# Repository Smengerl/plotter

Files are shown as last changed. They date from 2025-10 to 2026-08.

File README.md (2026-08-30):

# G-code Pen Plotter







> ⚠️ **Work in progress.** This project is under active development — hardware
> wiring, firmware configuration and the software pipeline are all still
> changing, and some documents have drifted apart during past refactors.
> Known contradictions and errors are tracked in **[TODO.md](TODO.md)**;
> inline `TODO:` markers in the docs point there. Expect updates.

This plotter draws vector graphics in G-code format using a pen. It is compatible with pens up to 11 mm in diameter, relies on inexpensive and widely available components, and uses a mostly 3D-printed frame with a few off-the-shelf mechanical parts. A set of test cases guides the user to verify the functionality of each hardware component before running GRBL.

The plotter's firmware is based on GRBL v1.1, which is a widely used open-source CNC controller firmware.
It comes with a GUI toolset to transform images provided by the user to drawings in different styles via AI (technical drawing, pencil drawing, oil painting etc.) to send them to the plotter for drawing.

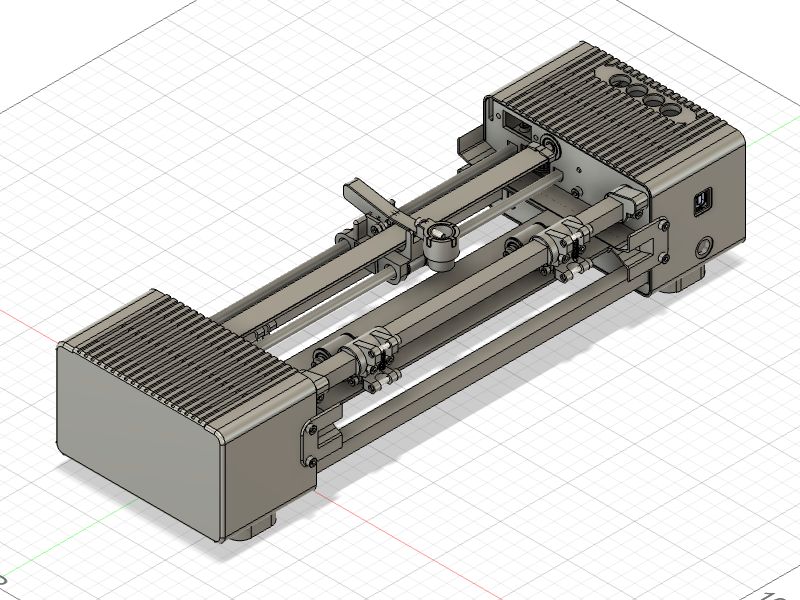
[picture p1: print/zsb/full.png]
Assembly overview


# Table of contents

- [Overview](#overview)
- [Features](#features)
- [Bill of Materials](#bill-of-materials)
- [Assembly](#assembly)
- [Electronics](#electronics) — see [electronics.md](electronics.md) for full details
- [Firmware](#firmware) — see [firmware/README.md](firmware/README.md) for full details
- [Testing & commissioning](#testing) — see [testing.md](testing.md) for the full procedure
- [Software for host computer](#software-for-host-computer) — see [pipeline/README.md](pipeline/README.md) for full details
- [Acknowledgements](#acknowledgements)
- [License](#license)

## Overview

This pen plotter is meant for hobbyists and makers who want a low-cost machine to draw vector artwork on paper. It uses two stepper-driven axes, a simple pen carriage with a lift mechanism via solenoid for automated pen up/down control. Most structural parts are 3D-printed and a number of standard mechanical parts (rods, bearings, springs, belt and pulleys) complete the build.

## Features

- Compatible with pens up to 11 mm diameter
- Mostly 3D-printed components for easy reproduction
- Designed for A4-sized paper by default (adjustable)
- Open-source firmware based on GRBL v1.1
- Test suite to verify hardware functionality before running GRBL
- GUI toolset for image-to-G-code conversion with AI-based drawing styles (technical, pencil, oil painting etc.)

## Bill of Materials

Below are the main 3D-printed parts and standard hardware used in the project. See the [full BOM](BOM.md) and the `print/` directory for the source STL/PNG files and visual references.

### 3D-printed parts (selected)

Refer to the `print/stl/` and `print/png/` folders for all printable parts and preview images.

- `frame_front.stl`, `frame_back.stl` — frame halves
- `housing_front.stl`, `housing_back.stl`, `housing_feet.stl` — optional housing
- `carriage_penholder_base.stl`, `carriage_penholder_connector_screw.stl` — carriage and pen holder
- `flat_steel_flange.stl`, `flat_steel_lever.stl` — parts that interface with the steel pen-raising strip
- `paper_bail_*.stl` — paper bail and rollers
- `paper_guide_front.stl`, `paper_guide_back.stl` — paper gudie
- `shaft_end_flange.stl`, `shaft_connector_flange.stl` — shaft support parts
- `solenoid_slider.stl` — slider to make the pull solenoid a push solenoid (optional)
- `cable_management.stl` — optional cable management clips

### Standard hardware (selected)

- 12 mm square rods
- 6 mm round rods
- 12 mm steel shaft
- 2x 6mm linear ball bearings
- 2x NEMA 17 stepper motors
- 2GT 5mm timing belt, timing pulley and idler pulley
- Assorted M2/M3/M4 screws and nuts (details in original BOM)
- Bearings: F624ZZ bearings used in the rollers
- Springs: compression and extension springs as needed for pen lift and paper drive
- Pull solenoid 12 V (example: TAU-0530)

For a complete part list including quantities and McMaster/AliExpress references, see the original [BOM](BOM.md) in the repository.

## Assembly

The repository contains step-by-step photos and GIFs in `print/zsb/` that show how parts fit together. The high-level assembly steps are:

1. Prepare the back frame: press in M3 nuts, install bearings, fit the timing-belt pulley and mount the optical endstop and solenoid.

2. Prepare the front frame: press in M3 nuts, install bearings, attach stepper motor and shaft coupler, and mount the drive pulley and endstop.

3. Join both frame halves: insert the paper guide rods, shaft, and the movable flat-steel strip used for pen lifting.

Fully assembled lever mechanism:
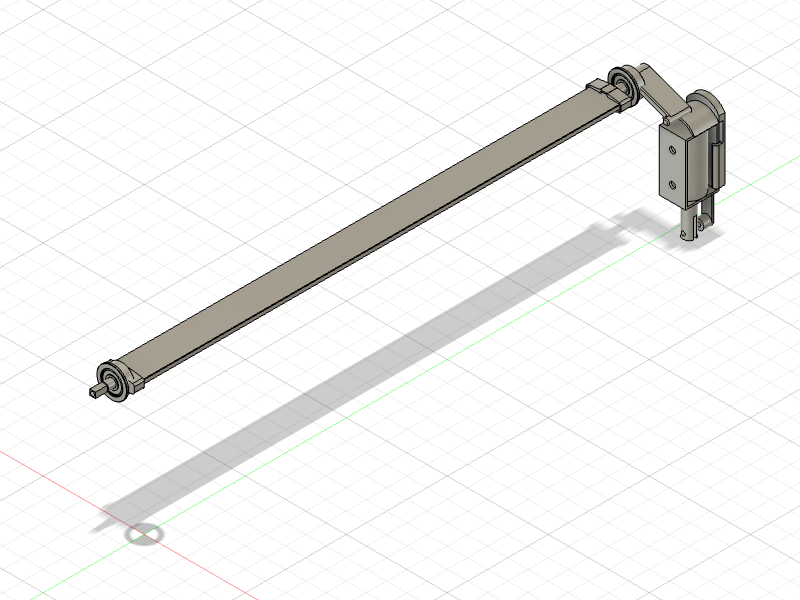
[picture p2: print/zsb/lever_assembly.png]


Fully assembled drive shaft:
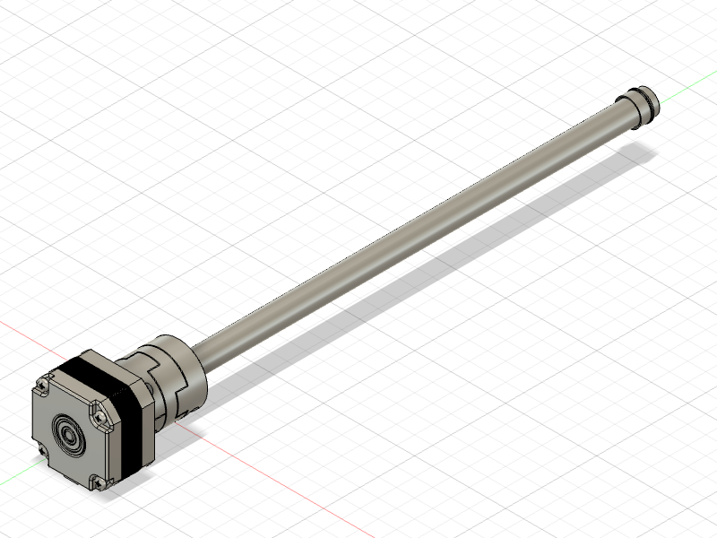
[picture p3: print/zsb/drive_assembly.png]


4. Slide the carriage onto the guide rods and secure the timing belt to the carriage. Fit the belt around the drive and idler pulleys and tension appropriately.

Fully assembled carriage and timing belt mechanism:
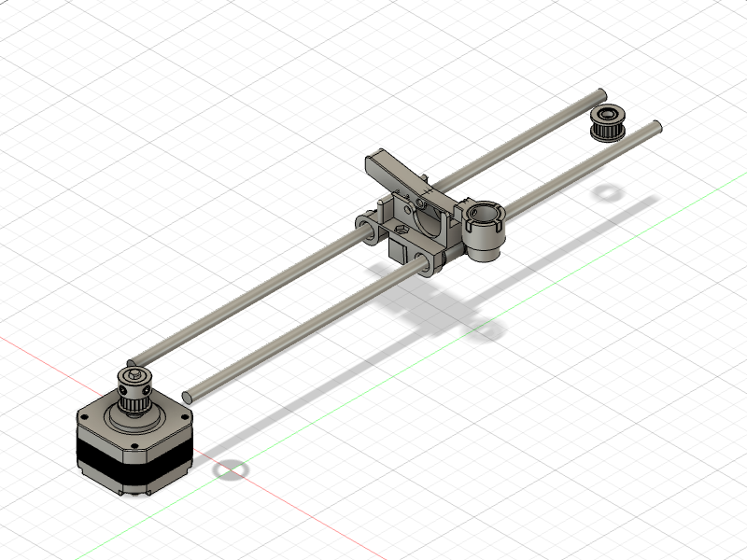
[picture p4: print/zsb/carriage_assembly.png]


5. Assemble and install the paper bail rollers and springs that hold and move the paper.

Detail for each paper bail roller:
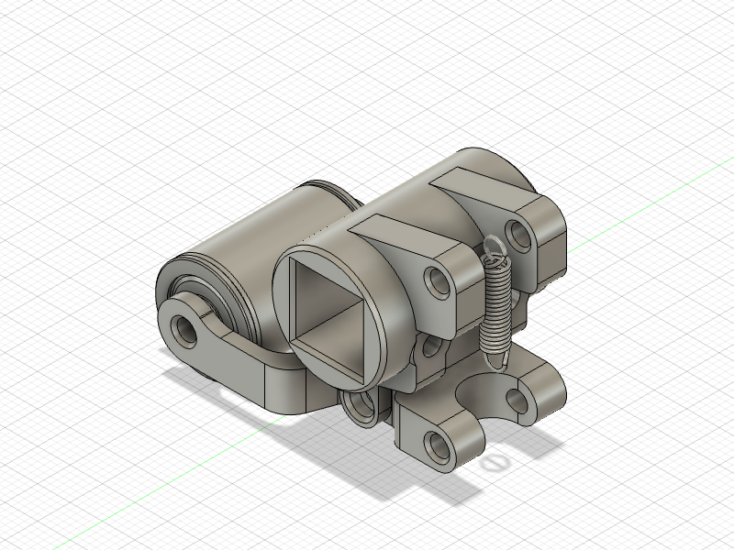
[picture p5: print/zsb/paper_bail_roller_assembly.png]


Fully assembled paper bail:
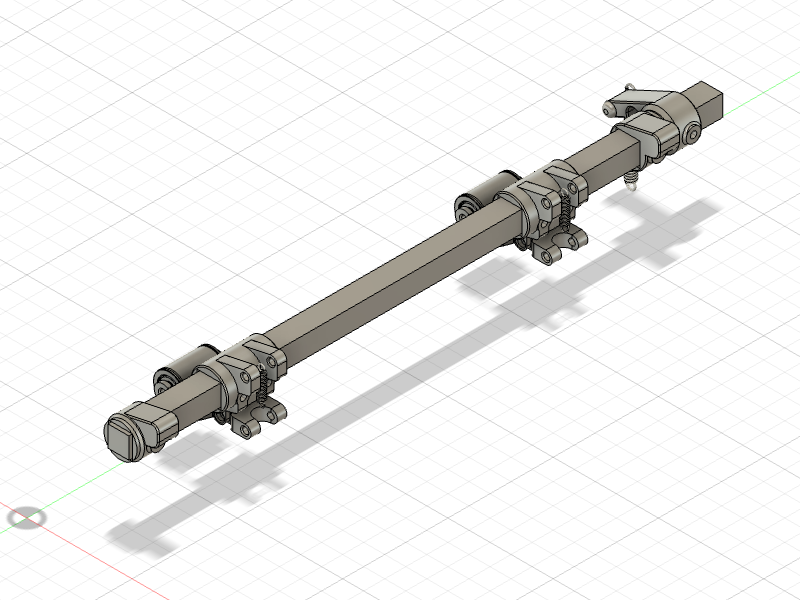
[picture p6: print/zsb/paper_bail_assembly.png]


6. Optionally assemble and attach the housing halves for a finished enclosure.

Important: some assembly steps (press-fitting nuts and bearings, re-threading printed holes) may require light machining or careful rework for reliable operation.

## Electronics

The electronics are intentionally simple: an Arduino Uno with a CNC Shield v3 and two A4988 stepper drivers.
A solenoid controlled via a MOSFET handles pen lift.

For full details on wiring, pin mapping, microstepping, endstops and the solenoid circuit see **[electronics.md](electronics.md)**.

Assembly steps:

1. Route the stepper motor and endstop cables through the frame openings into the enclosure.
2. Secure cables with cable ties and cable management clips to avoid interference with moving parts.
3. Prepare the PCB holder by pressing in the M3 nuts. Screw the Arduino to it. Add the CNC Shield and the stepper drivers. Finally slide the PCB holder over the rods.
4. Assemble all wires according to [electronics.md](electronics.md).
5. Attach the housing and fix it to the PCB holder and rods with M3 screws. Make sure the USB port and power jack are accessible.

## Firmware

The plotter runs [GRBL](https://github.com/gnea/grbl) v1.1 on the Arduino Uno.
All firmware sources live in `firmware/`; GRBL is included as a Git submodule under `firmware/grbl/`.

For build instructions, flashing, GRBL parameter setup and G-code tooling see **[firmware/README.md](firmware/README.md)**.

Quick start:

```bash
git clone --recurse-submodules https://github.com/Smengerl/plotter.git
cd plotter/firmware
pio run -t upload   # build and flash
pio device monitor  # open serial console at 115200 baud
```

## Testing

**[testing.md](testing.md) is the single source for the whole test and
commissioning sequence** — from the standalone hardware checks, through
flashing GRBL, to a full end-to-end plot:

| Phase | What it covers |
| --- | --- |
| [Phase 0](testing.md#phase-0--prerequisites) | Assembly, wiring and software install (pointers) |
| [Phase 1](testing.md#phase-1--standalone-arduino-tests-no-grbl) | Standalone Arduino sketches TC1–TC4 (no GRBL) |
| [Phase 2](testing.md#phase-2--grbl-integration-tests) | GRBL integration tests TC5-G–TC9-G |
| [Phase 3](testing.md#phase-3--pipeline-software-tests) | Host-side Python pipeline tests TC-P1–TC-P3 |
| [Phase 4](testing.md#phase-4--full-system-end-to-end-plot) | Full system end-to-end plot TC-E1–TC-E3 |

## Software for host computer

A set of CLI tools to send G-code files to the plotter is included in pipeline.
The tool allows to configure individual processing pipelines by pure configuration without changing the code for images including adaptation of styles via prompt to a provided image, the necessary vectorization and sending the G-code.

A GUI frontend is provided for convenient usage of these mechanism including management of the raw images, applying various pipelines to them, previewing the adapted images and eventually sending the images to the plotter.

See **[pipeline/README.md](pipeline/README.md)** for the full procedure.

## Acknowledgements

The firmware is built on [GRBL](https://github.com/gnea/grbl) by Sungeun K. Jeon
(Gnea Research LLC), Simen Svale Skogsrud and Jens Geisler. Thanks to the
open-source community and the suppliers of affordable components. Third-party
notices are collected in [NOTICE](NOTICE).

## Development

Contributions are welcome.  
See `CONTRIBUTING.md` for details and follow the `CODE_OF_CONDUCT.md` when contributing.

All .stl, .png and assembly pictures are automatically exported via my Fusion add-in, see [here](https://github.com/smengerl/fusion-exporter)

## License

This project is **licensed per component** — the parts have different origins
and obligations:

| Part | License | Why |
| --- | --- | --- |
| Firmware — [`firmware/`](firmware/LICENSE) (except the submodule) | **GPL-3.0-or-later** | It is a derivative of [GRBL](https://github.com/gnea/grbl): it reuses GRBL headers, is compiled and linked into one binary with the GRBL sources, and [`firmware/src/grbl_main_shim.c`](firmware/src/grbl_main_shim.c) is copied from GRBL's `main.c`. GRBL is GPLv3, so the combined firmware must be too. |
| GRBL — [`firmware/grbl/`](firmware/grbl/COPYING) | **GPL-3.0** | Upstream `gnea/grbl`, included unchanged as a git submodule. |
| Host software — [`pipeline/`](pipeline/LICENSE) | **MIT** | Separate Python program that only talks to GRBL over the serial port (arm's-length, no shared code), so it is not bound by GRBL's license and is kept permissive. |
| Hardware design (`print/`, `BOM.md`) and documentation (`*.md`) | **CC BY-SA 4.0** — see [`LICENSE.txt`](LICENSE.txt) | Not software; ShareAlike keeps derivative hardware/docs open. |

Each area carries its own `LICENSE` file and, for `firmware/`, SPDX headers in
the source. Third-party attributions: [NOTICE](NOTICE).

## Authors

- Simon Gerlach <https://github.com/Smengerl>

---

If something in this README is missing or unclear, please open an issue in the repository so the instructions can be improved.

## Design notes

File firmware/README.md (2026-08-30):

# GRBL Firmware

> ⚠️ **Work in progress** — see [../TODO.md](../TODO.md) for known open issues
> (`$5` limit-pin polarity, GRBL banner text, on-hardware verification).

This document describes the GRBL setup for the G-code Pen Plotter.  
GRBL v1.1 runs on the Arduino Uno via the Arduino CNC Shield v3.  
All firmware sources live in the `firmware/` directory. GRBL itself is included as a Git submodule under `grbl/`.

This file is **firmware reference only** (layout, build, flash, GRBL
parameters). The hardware and firmware **test procedure** lives in
[../testing.md](../testing.md).

## Table of contents
- [Repository layout](#repository-layout)
- [Prerequisites](#prerequisites)
- [First-time setup](#first-time-setup)
- [Build and flash](#build-and-flash)
- [Serial monitor / GRBL console](#serial-monitor--grbl-console)
- [Key GRBL settings](#key-grbl-settings-first-run-checklist) — first-run checklist
- [GRBL settings & calibration](GRBL.md) — full `$` reference + tuning
- [Hardware & firmware tests](#hardware--firmware-tests) — pointer to `testing.md`

## Repository layout

```
firmware/
├── platformio.ini        ← PlatformIO project (build & flash config)
└── src/
    ├── config.h          ← Plotter compile-time overrides (see below)
    ├── main.cpp          ← Arduino-framework entry point (calls grbl_main)
    └── grbl_main_shim.c  ← Bridges GRBL's main() to grbl_main() to avoid linker conflict
└── grbl/                 ← Git submodule: gnea/grbl (do not edit)
```

### How `src/config.h` is applied

`platformio.ini` force-includes it into every translation unit
(`build_flags = ... -include src/config.h`). It `#include`s the stock
`grbl/grbl/config.h` unchanged and then overrides only the settings this
machine needs (`HOMING_CYCLE_0` = X only; asserts `VARIABLE_SPINDLE`).

**Only compile-time options belong in `config.h`.** Machine parameters
(steps/mm, feed rates, travel, limit inversion, homing enable/direction)
are `$` settings stored in EEPROM — set them on the board, see
[Key GRBL settings](#key-grbl-settings-first-run-checklist).

## Prerequisites

| Tool | Purpose |
|---|---|
| [PlatformIO CLI](https://platformio.org/install/cli) or [PlatformIO IDE (VS Code extension)](https://platformio.org/install/ide?install=vscode) | Build and flash |
| USB cable (USB-A ↔ USB-B) | Connect Arduino Uno to PC |

No additional toolchain setup is needed — PlatformIO downloads the AVR toolchain automatically on first build.

## First-time setup

```bash
# 1. Clone the repository with the GRBL submodule
git clone --recurse-submodules https://github.com/Smengerl/plotter.git
cd plotter

# If you already cloned without --recurse-submodules:
git submodule update --init --recursive
```

## Build and flash

```bash
cd firmware

# Build only (no board required)
pio run

# Build AND flash (board must be connected via USB)
pio run -t upload

# Override the serial port if auto-detection fails:
pio run -t upload --upload-port /dev/tty.usbmodem*   # macOS
pio run -t upload --upload-port /dev/ttyUSB0          # Linux
pio run -t upload --upload-port COM3                   # Windows
```

## Serial monitor / GRBL console

```bash
cd firmware
pio device monitor   # 115200 baud, 8N1
```

After reset you should see the GRBL welcome banner:
```
Grbl 1.1h ['$' for help]
```

Type `$` to list all available commands, or `$$` to print current parameter values.

## Key GRBL settings (first-run checklist)

**Required after flashing a fresh chip.** The compiled-in power-up defaults
are GRBL's generic values (250 steps/mm etc.); the plotter values live only
in EEPROM. Connect to the serial monitor and set:

```gcode
$100=5       ; X steps/mm
$101=5       ; Y steps/mm
$110=3000    ; X max rate (mm/min)
$111=3000    ; Y max rate (mm/min)
$120=200     ; X acceleration (mm/s²)
$121=200     ; Y acceleration (mm/s²)
$130=220     ; X max travel (mm) — PLACEHOLDER, teach it (see below)
$131=300     ; Y max travel (mm) — soft-limit bound only (Y has no endstop)
$5=1         ; invert limit pins — UNVERIFIED, check module polarity (see ../TODO.md)
$20=0        ; Soft limits OFF (enable to 1 only after $130 is taught)
$21=0        ; Hard limits OFF (enable to 1 after wiring is verified)
$22=1        ; Homing cycle ON
$23=0        ; Homing direction: X toward MIN
$24=50       ; Homing feed rate (mm/min)
$25=800      ; Homing seek rate (mm/min)
$27=5        ; Homing pull-off (mm)
$30=1000     ; Max spindle "RPM" → maps S1000 to full solenoid drive
$31=0        ; Min spindle "RPM"
```

`$H` homes the **X axis only** — Y has no endstop, Z is disabled. GRBL cannot
tell X_MIN from X_MAX (they share one limit pin), so after homing you must
**measure the X length and store it in `$130`** — see
[testing.md → TC5b-G "Teach the X-axis length"](../testing.md#tc5b-g--teach-the-x-axis-length).

The full `$` reference, calibration procedures (steps/mm, direction,
acceleration, squaring) and per-setting notes are in
**[GRBL.md](GRBL.md)**. The electrical layout is in
[electronics.md → Machine configuration](../electronics.md#machine-configuration-canonical).

### Steps/mm calculation

```
steps/mm = (200 steps/rev × 1 full step) / (20 teeth × 2 mm/tooth) = 5
```

No MS jumpers are installed on the CNC Shield — the A4988 operates in full-step mode.  
Adjust `$100` / `$101` if you change the pulley tooth count or enable microstepping.

### Pen lift G-code

The solenoid is controlled via the GRBL spindle output (see [electronics.md](../electronics.md) for wiring details).

Note: this repository's G-code profile (`pipeline/configs/grbl_a4_pen.toml`) is configured for an "inverted" solenoid mounting where the solenoid being ENERGIZED = pen UP (lift). That means:

- `M3 S1000` → energize solenoid → pen UP (repo default)
- `M5`        → de-energize solenoid → pen DOWN (spring return)

If your hardware is wired the other way (energized = pen DOWN), swap the M3/M5 commands in the G-code profile or rewire the solenoid/MOSFET accordingly.

## Hardware & firmware tests

The full test procedure — standalone hardware sketches and GRBL integration
tests — lives in **[../testing.md](../testing.md)**:

| Phase | Content | Precondition |
| --- | --- | --- |
| [Phase 1](../testing.md#phase-1--standalone-arduino-tests-no-grbl) | Standalone sketches TC1–TC4 (no GRBL) | Wiring complete |
| [Phase 2](../testing.md#phase-2--grbl-integration-tests) | GRBL integration tests TC5-G–TC9-G | Phase 1 passed, GRBL flashed |

Run Phase 1 first, then flash GRBL (see [Build and flash](#build-and-flash)),
then Phase 2.

The Phase 1 sketches live in `firmware/test/`; the PlatformIO env names match
the TC numbers:

```bash
cd firmware
pio run -e tc1_x_axis     -t upload   # TC1 — X-axis movement
pio run -e tc2_endstops   -t upload   # TC2 — endstops (X_MIN + X_MAX)
pio run -e tc3_y_axis     -t upload   # TC3 — Y-axis movement
pio run -e tc4_pen_lift   -t upload   # TC4 — pen lift (solenoid)
pio device monitor                    # 115200 baud
```

## See also

- Generating G-code from images (this project's pipeline) and third-party
  SVG→G-code / G-code sender tools: [../pipeline/README.md](../pipeline/README.md).

## License

The firmware in `src/` and `test/` is licensed **GPL-3.0-or-later**
([LICENSE](LICENSE)) — it is a derivative of and is compiled/linked together
with [GRBL](https://github.com/gnea/grbl) (GPLv3), so it inherits GRBL's
copyleft. `src/grbl_main_shim.c` is copied from GRBL's `main.c`. The
`grbl/` submodule is upstream GRBL, unchanged (`grbl/COPYING`). See the
[project-wide licensing table](../README.md#license).

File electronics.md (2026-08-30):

# Electronics Guide

> ⚠️ **Work in progress** — see [TODO.md](TODO.md) for known open issues
> (optical-endstop polarity / `$5`, solenoid holding-current tuning, and
> on-hardware verification).

This document covers the controller setup, wiring, pin mapping, and component details for the G-code Pen Plotter.
For firmware and GRBL configuration see [firmware/README.md](firmware/README.md).
For the hardware test procedure see [testing.md](testing.md).

## Table of contents

- [Machine configuration (canonical)](#machine-configuration-canonical)
- [Controller and shield](#controller-and-shield)
- [Stepper drivers](#stepper-drivers)
- [Power supply](#power-supply)
- [5 V / GND distribution board](#5-v--gnd-distribution-board)
- [Pin mapping](#pin-mapping-cnc-shield-v3--arduino-uno)
- [Microstepping jumpers](#microstepping-jumpers)
- [Wiring steps](#wiring-steps)
- [Hardware verification before flashing GRBL](#hardware-verification-before-flashing-grbl)
- [Endstops](#endstops)
- [Solenoid pen lift](#solenoid-pen-lift)

## Machine configuration (canonical)

**Single source of truth for the electrical build.** `firmware/src/config.h`,
the standalone test sketches (`firmware/test/`) and `testing.md` must all
match this table.

### Axes & endstops

| Axis | Function | Endstops | Homes? |
|---|---|---|---|
| X | Carriage | 2 × optical: **X_MIN + X_MAX** | yes → toward MIN |
| Y | Paper feed  | **none** | no |
| Z | (unused) | none | no |

- **Both X switches are wired in parallel onto the X_LIMIT pin (D9).** GRBL
  1.1 on the Uno has only one limit pin per axis, so it cannot tell X_MIN
  from X_MAX — it only ever reports "X limit tripped".
- `$H` homes X toward X_MIN. X_MAX is therefore only a hard-limit backstop.
  The usable X length must be **measured once and stored in `$130`** — see
  [testing.md → TC5b-G "Teach the X-axis length"](testing.md#tc5b-g--teach-the-x-axis-length).
- **Y has no reference.** `Y = 0` is wherever the axis sits at power-up or
  after `$X`. Load the paper, then treat that as the origin.
- Firmware: `HOMING_CYCLE_0 = (1 << X_AXIS)` (X only).

### Solenoid polarity

- **De-energized = pen DOWN (drawing).** This is the safe resting state — no
  coil current, no heat.
- **Energized (`M3`) = pen UP.** Never leave it energized: keep travel moves
  short and make sure every plot ends on `M5`
  (see `pipeline/configs/grbl_a4_pen.toml`).
- The G-code profile (`grbl_a4_pen.toml`) pulls the pen up at full drive
  (`M3 S1000`) then holds it at `M3 S350` (~35 % PWM) to limit coil heat —
  **the hold value still needs tuning on the real machine**, see
  [Solenoid pen lift](#solenoid-pen-lift).

## Controller and shield

- **Arduino Uno** (ATmega328P) running GRBL v1.1
- **Arduino CNC Shield v3** stacked on top of the Uno

Only **2 of the 4 possible axes** on the CNC Shield are used:

- **X axis** -- carriage movement via timing belt, with X_MIN + X_MAX optical endstops
- **Y axis** -- paper feed (no endstop)

## Stepper drivers

- **A4988** (or DRV8825 as drop-in replacement) for X and Y axes
- Attach heat sinks before first use
- Set the current limit via the trimmer pot **before** connecting motors under load -- set to ~70 % of your motor's rated current per phase

## Power supply

- **12 V DC** for NEMA 17 motors and solenoid
- Use a supply rated for the **combined peak current** of both stepper motors and the solenoid

### 12 V power supply

The 12 V supply connects to the **screw terminals on the CNC Shield** (labelled GND and V+), **not** to the Arduino's barrel jack.
From those terminals the voltage is passed through to the Arduino Uno's VIN pin via the shield's stacking header.
The Arduino's on-board voltage regulator converts VIN to the 5 V and 3.3 V rails used by the microcontroller and peripherals.
Use the 12 V supply to also power the MOSFET circuit power input as it will also drive the solenoid.

### USB and 12 V simultaneously

The Arduino Uno contains a power-path selector between the VIN from Stepper shield (and for its own barrel-jack) supply and the USB 5 V rail:

- **12 V via CNC Shield only** — the on-board regulator powers the Arduino; USB is not connected.
- **USB only (no 12 V via barrel jack/stepper shield)** — the Arduino runs from USB 5 V; the stepper drivers and solenoid are unpowered. Use this mode when flashing firmware without the motors connected.
- **Both 12 V and USB simultaneously** — this is the normal setup (UGS command sending from PC while the machine runs). The on-board Schottky diode prevents current from flowing back from the Arduino's 5 V rail into the host PC's USB port. No special precautions are needed.

## 5 V / GND distribution board

Several consumers need a regulated 5 V supply and a common GND:

| Consumer | Supply needed |
|---|---|
| Optical endstops (× 2, both on X) | +5 V, GND |
| MOSFET gate circuit | GND (gate pull-down) |
| Button / switch strip (if fitted) | +5 V, GND |

The CNC Shield exposes only a limited number of 5 V and GND pins on its headers, which is not enough for all consumers at once.
The recommended solution is a small **stripboard / perfboard distribution board**.
> Keep the total current draw of 5 V consumers well below 500 mA — the Arduino's on-board regulator (when powered from 12 V via the shield) can supply roughly 300–400 mA at 5 V before thermal throttling. Optical endstops typically draw < 20 mA each, so two endstops + a MOSFET pull-down are well within budget.

## Pin mapping (CNC Shield v3 -> Arduino Uno)

| Function | CNC Shield label | Arduino pin | Notes |
|---|---|---|---|
| X Step | X.STEP | D2 | |
| X Direction | X.DIR | D5 | |
| Y Step | Y.STEP | D3 | |
| Y Direction | Y.DIR | D6 | |
| Z Step (unused) | Z.STEP | D4 | |
| Z Direction (unused) | Z.DIR | D7 | |
| Stepper Enable | EN | D8 | active LOW |
| X endstops **X_MIN + X_MAX** | X- | D9 | both switches in parallel on this one pin |
| Y endstop *(none)* | Y- | D10 | GRBL `Y_LIMIT` — **leave unconnected** |
| Pen-lift solenoid | *(see below)* | **D11** | GRBL `SPINDLE_PWM` (needs `VARIABLE_SPINDLE`). Not on the "SpnEn" header — that is **D12**. Tap D11 at the **Z-endstop header** (hard-wired to D11 on the shield) or solder to the D11 pin. |
| *(Z_LIMIT — unused)* | Z- | D12 | relocated here by `VARIABLE_SPINDLE`; leave unconnected |
| Abort / Reset | -- | A0 | optional |
| Feed Hold | -- | A1 | optional |
| Cycle Start | -- | A2 | optional |

Verify pin assignments against `firmware/src/config.h` and the
[canonical table](#machine-configuration-canonical) above.

## Microstepping jumpers

**Leave all MS jumpers unpopulated** (MS1, MS2, MS3 all open) for **full-step operation**.
This matches `$100`/`$101` = 5 steps/mm (see
[firmware/README.md → Key GRBL settings](firmware/README.md#key-grbl-settings-first-run-checklist)).

| MS1 | MS2 | MS3 | Mode |
|-----|-----|-----|---|
| - | - | - | **Full step ← use this** |
| x | - | - | 1/2 |
| - | x | - | 1/4 |
| x | x | - | 1/8 |
| x | x | x | 1/16 |

## Wiring steps

1. Stack the CNC Shield v3 onto the Arduino Uno.
2. Leave all MS jumpers **unpopulated** (full-step operation, no jumpers needed).
3. Insert the A4988 stepper drivers for the X and Y slots; leave Z and A empty.
4. Attach heat sinks to the drivers.
5. Build and mount the 5 V / GND distribution board (see section above); connect it to the Arduino's 5 V and GND pins.
6. Route stepper motor and endstop cables through the frame openings into the enclosure.
7. Connect stepper motors to the X and Y terminals on the shield.
8. Connect **both X optical endstops** (X_MIN and X_MAX) to the **X-** endstop header (3-pin: GND / 5 V / Signal), signal lines combined onto the one pin; take GND and 5 V from the distribution board. Leave the **Y-** header unconnected.
9. Connect the solenoid MOSFET gate circuit to **D11** (tap the Z-endstop header or solder the D11 pin — see [pin mapping](#pin-mapping-cnc-shield-v3--arduino-uno)); connect the gate pull-down GND to the distribution board (see solenoid section below).
10. Connect the 12 V supply to the **screw terminals on the CNC Shield** (not the Arduino barrel jack).
11. Secure all cables with cable ties and cable management clips to avoid interference with moving parts.
12. Screw the Arduino/Shield assembly onto the PCB holder, slide it onto the rods, and attach the housing.
13. Make sure the USB port and the CNC Shield power terminals remain accessible.

## Endstops

The design uses **two optical endstops, both on the X axis** — `X_MIN` at the
home end and `X_MAX` at the far end. **The Y axis (paper feed) has no
endstop.** See the [canonical table](#machine-configuration-canonical).

- Both X switch signal lines are combined onto the single **X-** header pin
  (Arduino D9 = GRBL `X_LIMIT`). GRBL cannot distinguish the two; it only
  reports "X limit tripped". `$H` homes to X_MIN; the X_MAX position is
  taught into `$130` (see [testing.md → TC5b-G](testing.md#tc5b-g--teach-the-x-axis-length)).
- The **Y-** header stays unconnected. If hard limits (`$21=1`) are enabled,
  make sure the unused `Y_LIMIT` (D10) and `Z_LIMIT` (D12) pins are not
  floating into a "triggered" state — GRBL's internal pull-ups plus the
  correct `$5` value should leave them reading "clear".
- Optical endstops need the +5 V supply pin; mechanical microswitches only need GND and Signal.
- Internal pull-ups are enabled by GRBL; no external resistors needed for the signal line.

> **TODO** ([TODO.md](TODO.md)): the correct `$5` (invert limit pins) value is
> **unverified**. In GRBL 1.1, `$5=1` means "pin HIGH = triggered", `$5=0`
> means "pin LOW = triggered". Measure the real module output (beam clear vs.
> blocked) and set `$5` accordingly. Also confirm the two parallel X switches
> can share D9 without an output clash (open-collector / wired-OR).

## Solenoid pen lift

The solenoid is switched by the **GRBL spindle PWM output on D11** via an N-channel MOSFET.

**Which pin, and where to tap it.** GRBL's PWM/enable output is on **D11**
*only* when `VARIABLE_SPINDLE` is enabled in `firmware/src/config.h` (it is —
and it also moves the unused `Z_LIMIT` to D12). D11 is **not** the CNC Shield
"SpnEn" header (that pad is D12). Get D11 from:

- the **Z-endstop header** (`Z-` / `Z+`), which is hard-wired to D11 on the
  CNC Shield v3 — the same trick laser add-ons use; or
- a wire soldered directly to the Arduino D11 pin.

```
D11 --[100 Ohm]-- MOSFET gate
MOSFET drain     -- solenoid (-)
solenoid (+)     -- +12 V
Flyback diode    across solenoid coil (cathode -> +12 V)
MOSFET source    -- GND
gate --[10 kOhm]-- GND   (pull-down: MOSFET off at power-up)
```

- Use a logic-level N-channel MOSFET (e.g. IRLZ44N, 2N7000).
- The flyback diode (e.g. 1N4007) is **mandatory** to protect the MOSFET from inductive kick.
- Test the solenoid switching with a bench supply and current-limited setup before connecting to the full system.
- If you use an opto-isolated MOSFET *module* rather than a bare MOSFET, note
  that GRBL's spindle PWM carrier is ~1 kHz — fine at `S1000` (steady on), but
  a slow module may not pass a partial duty cycle cleanly (relevant only for
  the holding-current idea below).

### Polarity (this build)

**De-energized = pen DOWN (drawing).** No coil current in the resting state,
so no heat. Energized (`M3`) = pen UP. The solenoid **must not stay energized
for long** — the coil overheats.

| G-code | Solenoid | Pen |
|---|---|-----|
| `M3 S1000` | energized (PWM ~100 %) | UP |
| `M5` | de-energized | DOWN (drawing) |

### Reduced holding current

A pull solenoid needs full current only to *move* the plunger; *holding* it
needs far less. `pipeline/configs/grbl_a4_pen.toml` exploits the PWM on D11:
each pen-up pulls in at `M3 S1000`, dwells 50 ms, then drops to `M3 S350`
(~35 % duty), and every file ends on `M5`. This keeps the coil at roughly a
third of full power during travel.

- Firmware / settings: nothing to change (`VARIABLE_SPINDLE` gives PWM,
  `$30=1000` maps `S1000` → 100 %).
- **Tune `S350` on the real machine** (`S_HOLD` in the toml, used in both
  `document_start` and `line_end`): the lowest value that still holds the pen
  fully up during a travel move. Raise it if the pen drifts down; lower it if
  the coil still gets more than warm after a long plot.

## Hardware verification before flashing GRBL

Once the wiring above is complete, verify each subsystem independently with the
standalone test sketches in `firmware/test/` (X axis, endstops, Y axis, pen
lift) **before** flashing GRBL. They need no GRBL knowledge and print
PASS / FAIL on the serial monitor.

→ Procedure, expected values and failure diagnosis:
**[testing.md → Phase 1](testing.md#phase-1--standalone-arduino-tests-no-grbl)**.

Only proceed to flashing GRBL once all Phase 1 tests pass.

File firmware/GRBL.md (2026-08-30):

# GRBL settings & calibration

Every `$` setting below lives in the Arduino's EEPROM. Set one with
`$<n>=<value>`, list them all with `$$`. They survive re-flashing the
firmware; a fresh chip starts from GRBL's generic defaults, so run the
[first-run checklist](README.md#key-grbl-settings-first-run-checklist) once.

Back up your tuned values by saving the `$$` output somewhere.

Compile-time options (`HOMING_CYCLE_0`, `VARIABLE_SPINDLE`, CPU map) are **not**
`$` settings — they live in [`src/config.h`](src/config.h).

---

## Full settings table

Values in the "Plotter" column are this machine's targets. `—` = leave at the
GRBL default.

| `$n` | Meaning | Unit | Plotter | Notes |
|-----|---|---|---|---|
| `$0` | Step pulse time | µs | 10 | |
| `$1` | Step idle delay | ms | 25 | 255 = never disable (holds torque) |
| `$2` | Step port invert mask | bitmask | 0 | bit 0/1/2 = X/Y/Z |
| `$3` | Direction port invert mask | bitmask | 0 | flip a bit if an axis runs backwards (see calibration) |
| `$4` | Step enable invert | bool | 0 | A4988: 0 is correct |
| `$5` | Limit pins invert | bool | **?** | **UNVERIFIED** — `$5=1`: pin HIGH = triggered; `$5=0`: LOW = triggered. Measure your optical modules. |
| `$6` | Probe pin invert | bool | 0 | no probe |
| `$10` | Status report mask | bitmask | 1 | 1 = machine position |
| `$11` | Junction deviation | mm | 0.01 | |
| `$12` | Arc tolerance | mm | 0.002 | |
| `$13` | Report in inches | bool | 0 | metric |
| `$20` | Soft limits | bool | 0 → 1 | enable **only after `$130` is taught** |
| `$21` | Hard limits | bool | 0 → 1 | enable after the endstop wiring is verified (TC6-G/TC7-G) |
| `$22` | Homing cycle | bool | 1 | |
| `$23` | Homing dir invert mask | bitmask | 0 | X homes toward MIN |
| `$24` | Homing feed rate | mm/min | 50 | slow locate pass |
| `$25` | Homing seek rate | mm/min | 800 | fast search pass |
| `$26` | Homing debounce | ms | 250 | |
| `$27` | Homing pull-off | mm | 5 | must clear the switch |
| `$30` | Max spindle speed | "RPM" | 1000 | maps `S1000` → 100 % solenoid PWM |
| `$31` | Min spindle speed | "RPM" | 0 | |
| `$32` | Laser mode | bool | 0 | solenoid is not a laser |
| `$100` | X steps/mm | steps/mm | 5 | 2GT 20T pulley, A4988 full-step (see calibration) |
| `$101` | Y steps/mm | steps/mm | 5 | paper feed roller — measure and adjust |
| `$102` | Z steps/mm | steps/mm | — | Z disabled |
| `$110` | X max rate | mm/min | 3000 | |
| `$111` | Y max rate | mm/min | 3000 | |
| `$112` | Z max rate | mm/min | — | |
| `$120` | X acceleration | mm/s² | 200 | raise cautiously (see calibration) |
| `$121` | Y acceleration | mm/s² | 200 | |
| `$122` | Z acceleration | mm/s² | — | |
| `$130` | X max travel | mm | **taught** | measure it — see below / testing.md TC5b-G |
| `$131` | Y max travel | mm | 300 | no endstop; only bounds soft limits |
| `$132` | Z max travel | mm | — | |

---

## Calibration

### Direction (`$3`)

Run TC1 (X) and TC3 (Y), or TC7-G / TC8-G under GRBL. If an axis moves the
wrong way, flip its bit in `$3`:

| `$3` | inverted |
|---|---|
| 0 | none |
| 1 | X |
| 2 | Y |
| 3 | X and Y |

### Steps/mm (`$100` / `$101`)

The belt axis (X) is deterministic: `(200 steps/rev × microsteps) / (pulley
teeth × belt pitch)` = `(200 × 1) / (20 × 2)` = **5**. Verify it:

```gcode
G91
G1 X100 F1000     ; command 100 mm
G90
```

Measure the actual carriage travel `d`. Corrected value:
`$100_new = $100_old × 100 / d`. Repeat until it matches.

The **Y (paper feed) axis is not deterministic** — it depends on the roller
diameter and paper grip. Command `G1 Y100`, measure the paper advance, and
set `$101` the same way. Re-check with the paper you actually plot on.

### X-axis length (`$130`)

GRBL homes X against X_MIN only; X_MAX shares the pin. Measure the usable
length once and store it — full procedure in
[testing.md → TC5b-G](../testing.md#tc5b-g--teach-the-x-axis-length):

```gcode
$21=1                ; hard limits on, so X_MAX stops the jog
$H                   ; home X_MIN → X = 0
$J=G91 X20 F500      ; repeat until ALARM:1 (X_MAX)
?                    ; read MPos:X → usable length
$X
$130=<that minus ~3 mm>
$20=1                ; soft limits on
```

### Acceleration (`$120` / `$121`)

Start at 200 mm/s². Raise in ~100 mm/s² steps and run a fast move; if the
motor stalls or loses steps (drawing shifts), drop back one step. Higher
acceleration = faster plots but more vibration/ringing in the lines.

### Squaring / skew

If plotted rectangles come out as parallelograms, the X rail and the paper
feed are not perpendicular — that is mechanical, not a `$` setting. Check the
frame assembly and that the paper is fed straight.

### Solenoid (`$30` / `$31`)

`$30=1000` makes `S1000` = full PWM. The G-code profile
(`pipeline/configs/grbl_a4_pen.toml`) then uses `S1000` to pull the pen up
and `S350` to hold it — tune the hold value on the machine
(see [electronics.md → Solenoid pen lift](../electronics.md#solenoid-pen-lift)).

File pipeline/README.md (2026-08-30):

# Plotter Pipeline

> ⚠️ **Work in progress** — see [../TODO.md](../TODO.md) for known open issues.

Image-to-GCode pipeline for the pen plotter. Takes any photo or image as
input, applies an optional stylization step, vectorizes the result, and
outputs GCode for GRBL.

For where this fits in the overall bring-up, see
[../testing.md → Phase 3](../testing.md#phase-3--pipeline-software-tests).

---

## Table of Contents

1. [Quickstart](#quickstart)
2. [Installation](#installation)
3. [Entry Points](#entry-points)
4. [Config File Format](#config-file-format)
5. [Available Steps](#available-steps)
6. [Adding Custom Steps](#adding-custom-steps)
7. [Overriding Paths via CLI](#overriding-paths-via-cli)
8. [Alternative tools](#alternative-tools)
9. [License](#license)

---

## Quickstart

**Requirements:** Python 3.13 — install with `brew install python@3.13` on macOS.

> ⚠️ **Python 3.14 is not supported.** `vpype 1.15.x` requires Python `<3.14`.
> On macOS, `python3` often resolves to 3.14 — always use `python3.13` explicitly.

```bash
# 1. Create virtual environment and install dependencies
python3.13 -m venv .venv
.venv/bin/pip install --upgrade pip "setuptools<82" wheel
.venv/bin/pip install -e "pipeline/[gui]"   # core + web GUI; add ,diffusers for SD

# 2. Run the pipeline
.venv/bin/pipeline-run \
    --config pipeline/examples/standard_pipeline.yaml \
    --input  pipeline/input/testimage.png \
    --output output/result.gcode
```

The entry point commands carry the `.venv` interpreter in their shebang —
no manual `source .venv/bin/activate` required.

For models behind the HuggingFace gate (FLUX, SD3, some ControlNet weights):

```bash
.venv/bin/get-hf-token
```

---

## Installation

### Requirements

- Python **3.13** — vpype 1.15.x requires Python `>=3.11,<3.14`; Python 3.14 is **not supported**
  - macOS: `brew install python@3.13`
  - Linux: `sudo apt install python3.13 python3.13-venv`
  - Windows: download from [python.org](https://www.python.org/downloads/)

> ⚠️ On macOS, `python3` and `python` often resolve to the latest system Python (currently 3.14).
> Always use `python3.13` explicitly when creating the venv.

### Create the virtual environment

```bash
python3.13 -m venv .venv
.venv/bin/pip install --upgrade pip "setuptools<82" wheel
```

### Install the pipeline package

```bash
# Core only — the full CLI (all stylizers, vectorise, G-code, serial send)
.venv/bin/pip install -e pipeline/

# Core + web GUI server (recommended default)
.venv/bin/pip install -e "pipeline/[gui]"

# Add the Stable Diffusion backends (ControlNet, Img2Img)
.venv/bin/pip install -e "pipeline/[gui,diffusers]"

# Everything including dev/test tools
.venv/bin/pip install -e "pipeline/[gui,diffusers,dev]"
```

The `-e` flag installs in **editable mode** — changes to source files are
reflected immediately without reinstalling.

### Upgrade an existing installation

```bash
.venv/bin/pip install --upgrade pip "setuptools<82" wheel
.venv/bin/pip install -e "pipeline/[gui]"
```

To start completely fresh:

```bash
rm -rf .venv
python3.13 -m venv .venv
.venv/bin/pip install --upgrade pip "setuptools<82" wheel
.venv/bin/pip install -e "pipeline/[gui]"
```

### Windows

Replace `.venv/bin/` with `.venv\Scripts\` in all commands:

```powershell
python -m venv .venv
.venv\Scripts\pip install --upgrade pip "setuptools<82" wheel
.venv\Scripts\pip install -e "pipeline/[gui]"
.venv\Scripts\pipeline-run --config pipeline/examples/standard_pipeline.yaml
```

### GPU acceleration (CUDA)

After the standard install, replace the CPU torch build:

```bash
.venv/bin/pip install torch torchvision --index-url https://download.pytorch.org/whl/cu118
```

---

## Entry Points

After installation, pip registers four commands in `.venv/bin/`
(Windows: `.venv\Scripts\`). They require no shell activation.

### `pipeline-run` — Run the pipeline

```bash
.venv/bin/pipeline-run --config pipeline/examples/standard_pipeline.yaml --input pipeline/input/testimage.png
```

| Option | Description |
| --- | --- |
| `--config YAML` | Pipeline config file — **required** |
| `--input IMAGE` | Input image path (jpg, png, …) |
| `--output FILE` | Output file path (gcode, png, svg, …) |
| `--dry-run` | List and validate steps without executing |
| `-v, --verbose` | Debug-level logging |

### `pipeline-server` — GUI web server

Starts the FastAPI-based Pipeline Manager GUI at `http://127.0.0.1:8000`
(override with `--host` / `--port`).
Requires the `gui` extras: `.venv/bin/pip install -e "pipeline/[gui]"`.

```bash
.venv/bin/pipeline-server
.venv/bin/pipeline-server --port 9000
.venv/bin/pipeline-server --input-dir pipeline/input --tools-dir pipeline/configs
```

### `get-hf-token` — Save a HuggingFace token

```bash
.venv/bin/get-hf-token
```

Interactive prompt to store an API token for gated HuggingFace models.

### `pipeline-test` — Run the test suite

```bash
.venv/bin/pipeline-test                  # all tests
.venv/bin/pipeline-test -k stylize       # filter by name
.venv/bin/pipeline-test -x               # stop on first failure
```

---

## Config File Format

Pipelines are defined as YAML files (`.yaml`) or TOML files (`.toml`) in
`pipeline/configs/`. Both formats are supported.

### YAML pipeline config

A YAML config has a `steps` list. Each entry specifies the step name and its
parameters:

```yaml
# pipeline/configs/my_pipeline.yaml

steps:
  - step: load_image
    config:
      source_path: input/photo.jpg   # static path (overridable via --input)
      style_res: 1024                # max side length after scaling (0 = full)

  - step: stylise_canny
    config:
      canny_low: 50
      canny_high: 150

  - step: vectorise
    config:
      min_path_px: 10
      simplify_eps: 1.5

  - step: gcode_from_svg
    config:
      profile: grbl_a4_pen           # profile name from TOML file
      target_width_mm: 190.0
      target_height_mm: 277.0

  - step: save_gcode
    config:
      output_path: output/result.gcode   # static path (overridable via --output)

  - step: send_gcode
    enabled: false                       # disabled steps are skipped
    config:
      port: /dev/tty.usbmodem1101
      baud: 115200
```

#### Step entry keys

| Key | Required | Description |
| --- | --- | --- |
| `step` | ✅ | Step name — must match a key in `STEP_REGISTRY` |
| `config` | ✅ | Parameters for this step (can be `{}`) |
| `label` | — | Per-use display-name override, shown in log / GUI progress. Defaults to the step class's own name (e.g. `stylise_canny` → "Canny edge detection"). Only set it when a pipeline needs a more specific name (e.g. two `load_image` steps). |
| `enabled` | — | Set `false` to skip this step (default: `true`) |

### TOML GCode profile

`.toml` files define GCode output templates (vpype-gcode-compatible format).
They are referenced by `gcode_from_svg` steps via the `toml_path` /
`profile` config keys. The default profile is
`pipeline/configs/grbl_a4_pen.toml`.

Key TOML sections:

```toml
[gwrite]
default_profile = "my_profile"

[gwrite.my_profile]
unit          = "mm"
vertical_flip = true       # SVG origin top-left → GCode origin bottom-left
offset_x      = 5.0        # left margin in mm
offset_y      = 5.0        # bottom margin in mm

document_start = """..."""  # GCode header (initialization, homing, pen up)
segment_first  = """..."""  # emitted before first point of each path
segment        = "G1 X{x:.3f} Y{y:.3f}\n"
segment_last   = "G1 X{x:.3f} Y{y:.3f}\n"
line_end       = "...\n"    # emitted after each path (pen up)
document_end   = """..."""  # GCode footer
```

Available template variables: `{x}`, `{y}` (coordinates in mm).

---

## Available Steps

### Image I/O

#### `load_image`

Loads the source image from disk into `ctx.image` (PIL, RGB).
Must be the first step in any image pipeline.

| Config key | Default | Description |
| --- | --- | --- |
| `source_path` | — | Static input path. Overridden by `--input` at runtime. |
| `style_res` | `1024` | Max side length in pixels after scaling. `0` = full resolution. |

#### `save_image`

Writes `ctx.image` to disk. Useful for saving intermediate results or as
the final step of an image-only pipeline.

| Config key | Default | Description |
| --- | --- | --- |
| `output_path` | — | Static output path. Overridden by `--output` at runtime. |
| `quality` | `95` | JPEG quality (1–95). Ignored for other formats. |
| `compress_level` | `6` | PNG compression level (0–9). Ignored for other formats. |
| `overwrite` | `true` | Set `false` to raise an error if the file already exists. |

---

### Stylizers — OpenCV (no GPU required)

These steps convert `ctx.image` to a binary edge map (`ctx.intermediates["binary"]`).
They require only numpy and opencv — no GPU, no model download.

#### `stylise_canny`

Classic Canny edge detector.

| Config key | Default | Description |
| --- | --- | --- |
| `canny_low` | `50` | Lower hysteresis threshold |
| `canny_high` | `150` | Upper hysteresis threshold |
| `canny_blur` | `3` | Gaussian blur kernel size (odd number) |

#### `stylise_xdog`

eXtended Difference-of-Gaussians (XDoG) — produces clean, sketch-like
line drawings. Good general-purpose stylizer without neural networks.
(Winnemöller et al. 2012)

| Config key | Default | Description |
| --- | --- | --- |
| `sigma` | `0.4` | Inner Gaussian σ |
| `k_sigma` | `1.6` | Outer Gaussian factor (k × σ) |
| `epsilon` | `0.0` | Threshold; `0` = adaptive (90th percentile) |
| `phi` | `10.0` | Sharpness of the soft threshold |
| `threshold` | `20.0` | Final binarization threshold (0–255); `0` = skip |

#### `stylise_adaptive`

OpenCV adaptive threshold — good for documents and high-contrast images.

| Config key | Default | Description |
| --- | --- | --- |
| `block_size` | `11` | Neighborhood size (odd number ≥ 3) |
| `adapt_c` | `2.0` | Constant subtracted from the mean |
| `adapt_method` | `"gaussian"` | `"gaussian"` or `"mean"` |
| `adapt_blur` | `0` | Optional pre-blur kernel size (0 = disabled) |

---

### Stylizers — Neural Network (GPU recommended)

These steps download pre-trained models from HuggingFace on first use.
Their dependencies (`controlnet-aux`, `torch`, `torchvision`, `timm`,
`onnxruntime`) are already in the core `dependencies` — no extra needed
beyond the standard install. Only the diffusion stylizers below
(`stylise_controlnet`, `stylise_img2img`) additionally need `[diffusers]`.

All NN stylizers share these common config keys:

| Config key | Default | Description |
| --- | --- | --- |
| `device` | `"auto"` | `"auto"` (cuda › mps › cpu), `"cpu"`, `"cuda"`, `"mps"` |
| `threshold` | `128` | Binarization threshold applied to the model output (0–255) |
| `model_path` | `None` | Local model path; if `None` the HF repo is used |

#### `stylise_hed`

Holistically-nested Edge Detection (HED). Produces smooth, continuous
edge maps. Well-suited for portraits and organic shapes.

No additional config keys beyond the common ones above.

#### `stylise_dexined`

DexiNed-based edge detection (coarse lineart mode). Produces thick,
expressive contours.

No additional config keys beyond the common ones above.

#### `stylise_lineart`

ControlNet-v1.1 Lineart Preprocessor. Produces clean, fine-grain line
drawings — the recommended choice for most photos.

| Config key | Default | Description |
| --- | --- | --- |
| `lineart_coarse` | `false` | Coarse mode (thicker, bolder lines) |
| `lineart_detect_res` | `512` | Internal detection resolution |
| `lineart_image_res` | `512` | Output image resolution |

#### `stylise_informative`

Informative Drawings (Chan et al. CVPR 2022). Converts photos to clean,
artistic sketches that preserve semantic structure.

Tries ONNX first (`pip install onnxruntime`), falls back to PyTorch.

No additional config keys beyond the common ones above.

---

### Stylizers — Diffusion (HuggingFace token required for some models)

These steps require `diffusers`, `transformers`, `torch`, `accelerate`.
Install via `.venv/bin/pip install -e "pipeline/[gui,diffusers]"`.

For gated models (FLUX, SD3): run `.venv/bin/get-hf-token` first.

All diffusion stylizers share these common config keys:

| Config key | Default | Description |
| --- | --- | --- |
| `prompt` | — | Style guidance text |
| `negative_prompt` | `"blurry, low quality, distorted"` | What to avoid |
| `num_inference_steps` | `20` | Quality vs. speed trade-off |
| `guidance_scale` | `7.5` | How strongly the prompt is followed (1–15) |
| `device` | `"auto"` | `"auto"`, `"cpu"`, `"cuda"`, `"mps"` |
| `enable_model_cpu_offload` | `false` | Reduce VRAM at cost of speed |
| `binary_threshold` | `128` | Binarization threshold (0–255) |
| `hf_token_path` | `None` | Path to HF token file (default: `.hf_token` in project root) |

#### `stylise_controlnet`

Style transfer via ControlNet + Stable Diffusion 1.5. Applies a
text-guided artistic style while preserving structure from the input image.

| Config key | Default | Description |
| --- | --- | --- |
| `controlnet_type` | `"lineart"` | Structure guide: `canny`, `lineart`, `softedge`, `scribble`, `pose`, `depth`, `normal`, `seg` |
| `base_model` | `"runwayml/stable-diffusion-v1-5"` | HF model ID |

#### `stylise_img2img`

Lighter alternative to ControlNet — standard SD 1.5 img2img without
conditioning. Lower VRAM usage and faster than ControlNet.

| Config key | Default | Description |
| --- | --- | --- |
| `strength` | `0.7` | Modification intensity (0.0 = no change, 1.0 = full generation) |
| `model_id` | `"stable-diffusion-v1-5/stable-diffusion-v1-5"` | HF model ID |

---

### Vectorization

#### `vectorise`

Converts the binary edge map from a stylizer into a list of vector paths.
Can also be used directly after `load_image` without a stylizer (binarizes
`ctx.image` automatically in that case).

| Config key | Default | Description |
| --- | --- | --- |
| `min_path_px` | `10` | Minimum contour arc length in pixels — shorter paths are discarded |
| `simplify_eps` | `1.5` | Ramer-Douglas-Peucker tolerance in pixels (`0` = no simplification) |
| `binary_threshold` | `128` | Threshold used when binarizing `ctx.image` directly (no prior stylizer) |

---

### GCode Generation

#### `gcode_from_svg`  *(recommended)*

Generates GCode using a TOML profile (vpype-gcode-compatible format).
The default profile is `pipeline/configs/grbl_a4_pen.toml`.

| Config key | Default | Description |
| --- | --- | --- |
| `profile` | `"grbl_a4_pen"` | Profile name inside the TOML file |
| `toml_path` | built-in default | Path to TOML profile file |
| `target_width_mm` | `190.0` | Drawing width in mm (A4 minus margins) |
| `target_height_mm` | `277.0` | Drawing height in mm (A4 minus margins) |
| `keep_aspect` | `true` | Maintain image aspect ratio |
| `linesort` | `true` | Optimize path order to minimize travel distance |

#### `gcode_gen`  *(legacy)*

Generates GCode with a built-in coordinate transformation — no TOML profile.
Use `gcode_from_svg` for new pipelines; `gcode_gen` is kept for
backward compatibility.

| Config key | Default | Description |
| --- | --- | --- |
| `target_width_mm` | `180.0` | Drawing width in mm |
| `target_height_mm` | `250.0` | Drawing height in mm |
| `origin_x` | `5.0` | Left margin in mm |
| `origin_y` | `5.0` | Bottom margin in mm |
| `keep_aspect` | `true` | Maintain aspect ratio |
| `feedrate_draw` | `1500` | Drawing feedrate in mm/min |
| `feedrate_travel` | `3000` | Travel feedrate in mm/min |
| `pen_down_cmd` | `"M5"` | GRBL command for pen down |
| `pen_up_cmd` | `"M3 S1000"` | GRBL command for pen up |
| `pen_delay_ms` | `100` | Wait after pen down (ms) |

---

### GCode Output

#### `save_gcode`

Writes the GCode lines to a file. Output path resolution:

1. `ctx.metadata["output_path"]` — set via `--output` at runtime
2. `config["output_path"]` — static path in the YAML config

| Config key | Default | Description |
| --- | --- | --- |
| `output_path` | — | Static fallback output path |

#### `send_gcode`

Streams GCode to a GRBL controller over serial using `pygrbl_streamer`.
Used by `pipeline/configs/plotter.yaml`.

The step **fails the pipeline** (raises, so the CLI exits non-zero and the
GUI marks the job `error`) if GRBL reports an `error:` / `ALARM:` during
streaming, if the device disconnects, or if GRBL is not back in `Idle`
afterwards. `pygrbl_streamer` on its own only logs these.

| Config key | Default | Description |
| --- | --- | --- |
| `port` | `"/dev/tty.usbmodem1101"` | Serial port |
| `baud` | `115200` | Baud rate |
| `dry_run` | `false` | Open the port and validate, but do not send / move |
| `completion_timeout` | `300` | Seconds to wait for GRBL to return to `Idle` after the last line |

---

## Adding Custom Steps

### 1. Create the step class

Create `pipeline/steps/my_step.py` and inherit from `PipelineStep`:

```python
# pipeline/steps/my_step.py
from __future__ import annotations
from pipeline.core.base import ImageContext, PipelineStep

class MyStep(PipelineStep):
    """
    One-line description.

    Config keys   Default   Description
    ------------------------------------
    my_param      42        What this controls.
    """

    name = "My step"   # human-readable default for logs / GUI progress

    def requires(self) -> list[str]:
        # Declare which context keys must be present before this step runs.
        # Valid values: "image", "intermediates.binary", "intermediates.paths",
        #               "intermediates.gcode_lines"
        return ["image"]

    def process(self, ctx: ImageContext) -> ImageContext:
        my_param = self.config.get("my_param", 42)

        # Read from ctx
        image = ctx.image  # PIL.Image

        # Write results back
        import numpy as np
        ctx.intermediates["binary"] = np.zeros((100, 100), dtype="uint8")

        return ctx
```

### 2. Register the step

Add it to `STEP_REGISTRY` in `pipeline/core/registry.py`:

```python
from pipeline.steps.my_step import MyStep

STEP_REGISTRY: dict[str, type["PipelineStep"]] = {
    # ... existing entries ...
    "my_step": MyStep,
}
```

### 3. Use it in a config

```yaml
steps:
  - step: load_image
    config:
      source_path: input/photo.jpg

  - step: my_step
    config:
      my_param: 99

  - step: vectorise
    config: {}
```

### 4. Add tests

Create `pipeline/tests/test_my_step.py`:

```python
from pipeline.core.base import ImageContext
from pipeline.steps.my_step import MyStep
from PIL import Image

def test_my_step_basic():
    step = MyStep(config={"my_param": 99})
    ctx = ImageContext()
    ctx.image = Image.new("RGB", (64, 64), color=(128, 128, 128))
    result = step.process(ctx)
    assert "binary" in result.intermediates
```

Run all tests:

```bash
.venv/bin/pipeline-test
```

---

## Overriding Paths via CLI

The `load_image` and `save_gcode` / `save_image` steps support a
**two-level path resolution** that lets the CLI override static paths
defined in the YAML config at runtime.

### Priority order

| Priority | Source | How to set |
| --- | --- | --- |
| 1 (highest) | `ctx.metadata["source_path"]` | `--input IMAGE` on the CLI |
| 2 | `config["source_path"]` in YAML | Static path in the config file |

The same pattern applies for `output_path`:

| Priority | Source | How to set |
| --- | --- | --- |
| 1 (highest) | `ctx.metadata["output_path"]` | `--output FILE` on the CLI |
| 2 | `config["output_path"]` in YAML | Static path in the config file |

### Examples

**Config has a static path, CLI overrides it:**

```yaml
# pipeline/configs/my_pipeline.yaml
steps:
  - step: load_image
    config:
      source_path: input/default.jpg   # used when no --input is given
  - step: save_gcode
    config:
      output_path: output/default.gcode
```

```bash
# Override both paths at runtime:
.venv/bin/pipeline-run \
    --config pipeline/configs/my_pipeline.yaml \
    --input  input/my_photo.jpg \
    --output output/my_photo.gcode
```

**Config has no static path, path is required from CLI:**

```yaml
steps:
  - step: load_image
    config: {}   # no source_path → --input is required
  - step: save_gcode
    config: {}   # no output_path → --output is required
```

```bash
.venv/bin/pipeline-run \
    --config pipeline/configs/my_pipeline.yaml \
    --input  input/my_photo.jpg \
    --output output/my_photo.gcode
```

If neither the config nor the CLI provides a path, the step raises a
`ValueError` with a descriptive message.

### Programmatic override (Python API)

The same mechanism works when using the pipeline directly from Python:

```python
from pathlib import Path
from pipeline.core.base import ImageContext
from pipeline.core.runner import PipelineRunner

runner = PipelineRunner.from_yaml(Path("pipeline/configs/my_pipeline.yaml"))

ctx = ImageContext(metadata={
    "source_path": Path("input/my_photo.jpg"),
    "output_path": Path("output/my_photo.gcode"),
})

runner.run(ctx)
```

---

## Alternative tools

This pipeline is the supported path, but the plotter is a plain GRBL machine —
any SVG→G-code and G-code-sender toolchain works.

**SVG / vector graphics → G-code**

- [Inkscape](https://inkscape.org/) with the [Gcodetools](https://github.com/cnc-club/gcodetools) extension
- [vpype](https://github.com/abey79/vpype) + [vpype-gcode](https://github.com/plottertools/vpype-gcode) (this project uses both internally)
- [svg2gcode](https://github.com/sameer/svg2gcode) — simple CLI converter

Configure the tool to emit `M3 S1000` (pen UP) and `M5` (pen DOWN) at path
boundaries — see the profile in [configs/grbl_a4_pen.toml](configs/grbl_a4_pen.toml).

**Sending G-code to the plotter**

- [UGS (Universal G-code Sender)](https://universalgcodesender.com/) — cross-platform GUI
- [bCNC](https://github.com/vlachoudis/bCNC) — Python-based, feature-rich
- [CNCjs](https://cnc.js.org/) — browser-based, runs as a Node.js server

Connect at 115200 baud. Only one process may hold the serial port at a time.

---

## License

This pipeline is licensed **MIT** ([LICENSE](LICENSE)). It talks to GRBL only
over the serial port (no shared code with the GPLv3 firmware), so it is not
bound by GRBL's copyleft. See the
[project-wide licensing table](../README.md#license).

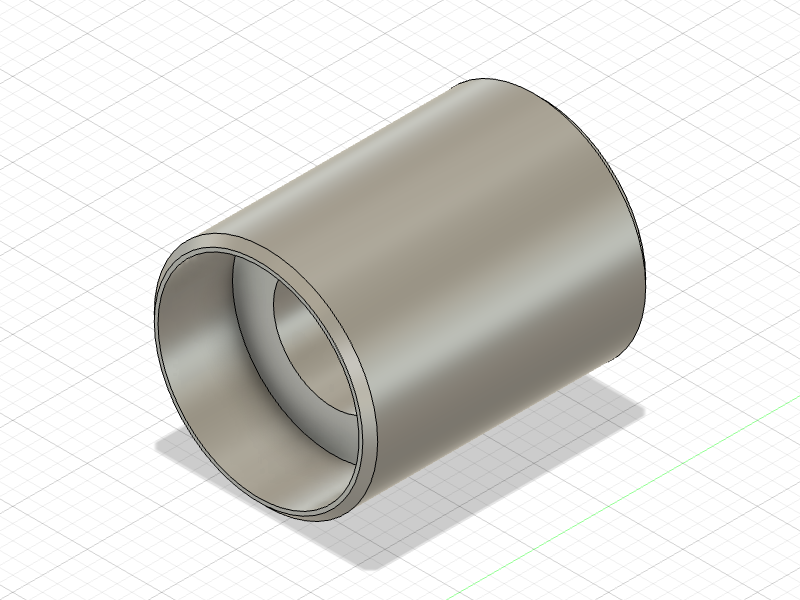
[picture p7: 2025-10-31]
print/png/paper_bail_roll.png

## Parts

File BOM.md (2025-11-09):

# Bill of Materials (BOM)

This file provides a Bill of Materials for the G-code Pen Plotter project. Quantities and approximate references are included. Use this as a shopping checklist or to create a parts order.

> Note: Supplier part numbers are examples where available. Replace links and part numbers with preferred suppliers.

> Note: Quantities below are the recommended default for an A4-capable plotter with 2 paper rollers. Adjust quantities and rod lengths for other paper sizes and more/less rollers.

## 3D-printed parts

All `.stl` files are in the `print/stl/` folder. Preview images are available in `print/png/` and assembly images in `print/zsb/`.

### 3D-Printed Parts

| Quantity | Part | Material | Notes |
| --- | ---- | --- | ----- |
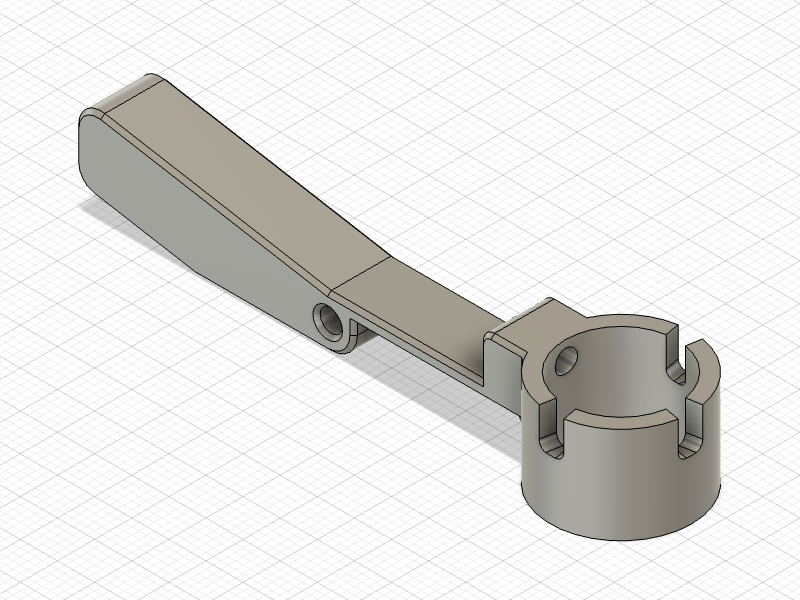
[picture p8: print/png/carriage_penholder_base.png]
| 1 | `./print/stl/carriage_penholder_base.stl`</BR> | PLA / PETG | Recutting the thread after printing recommended |
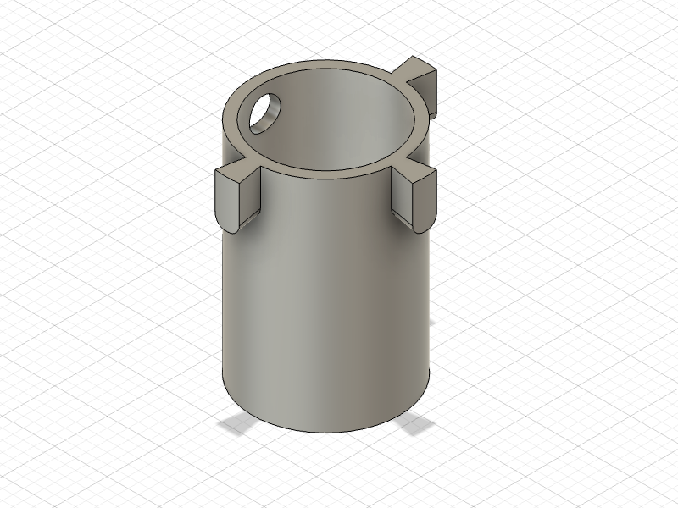
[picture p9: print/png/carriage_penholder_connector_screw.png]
| 1 | `./print/stl/carriage_penholder_connector_screw.stl`</BR> | PLA / PETG | |
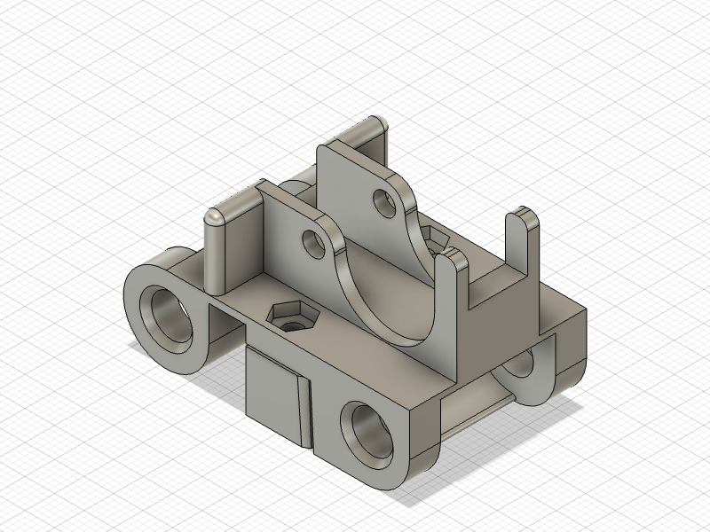
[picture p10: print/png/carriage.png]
| 1 | `./print/stl/carriage.stl`</BR> | PLA / PETG | |
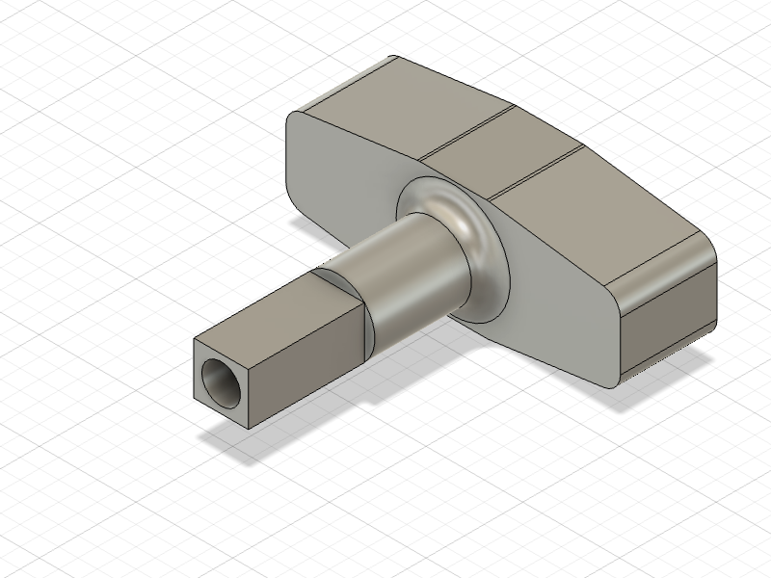
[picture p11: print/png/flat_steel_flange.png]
| 2 | `./print/stl/flat_steel_flange.stl`</BR> | PLA / PETG |  |
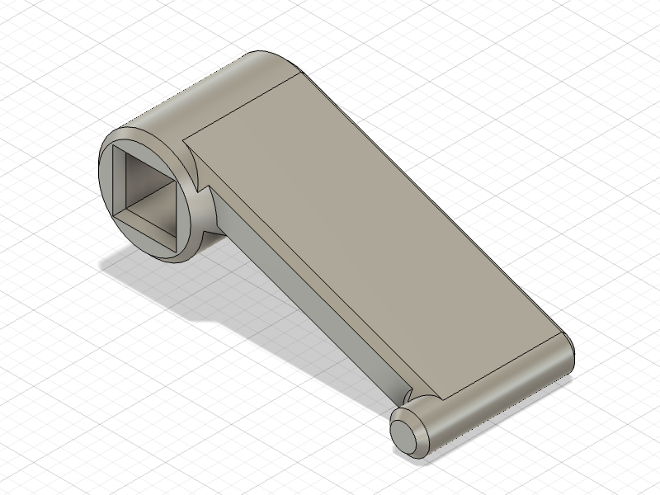
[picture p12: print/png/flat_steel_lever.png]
| 1 | `./print/stl/flat_steel_lever.stl`</BR> | PLA / PETG |  |
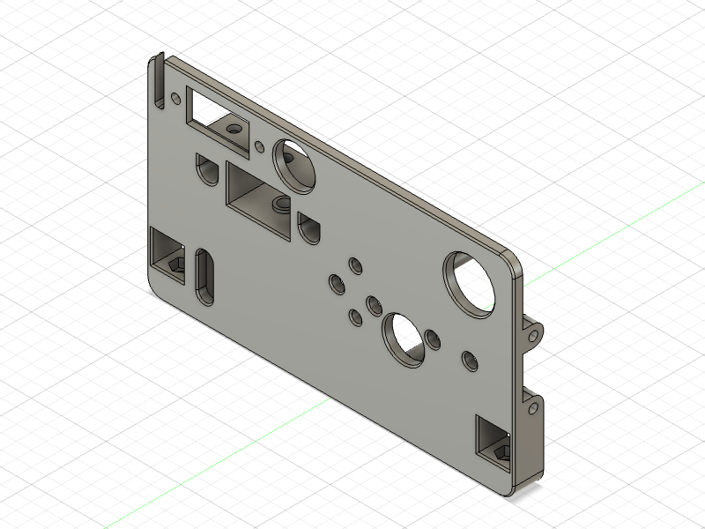
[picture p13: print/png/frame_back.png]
| 1 | `./print/stl/frame_back.stl`</BR> | PLA / PETG |  |
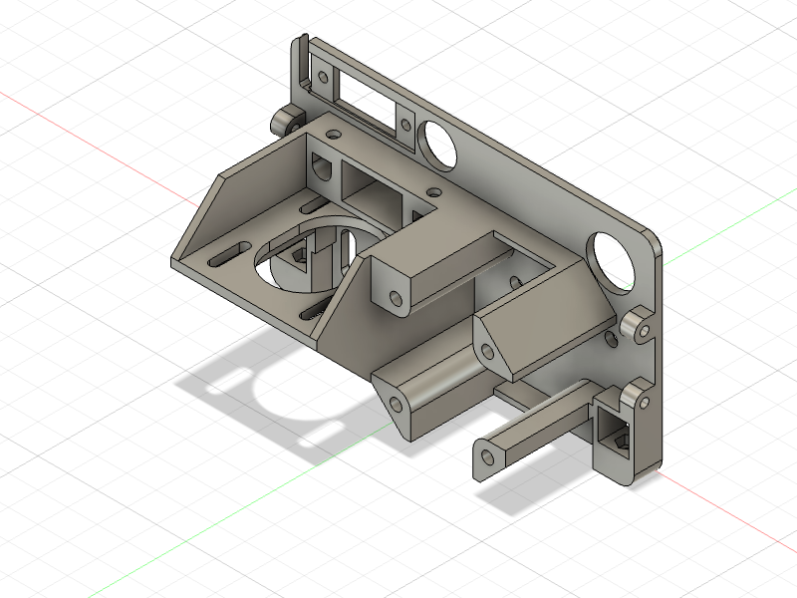
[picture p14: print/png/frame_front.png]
| 1 | `./print/stl/frame_front.stl`</BR> | PLA / PETG |  |
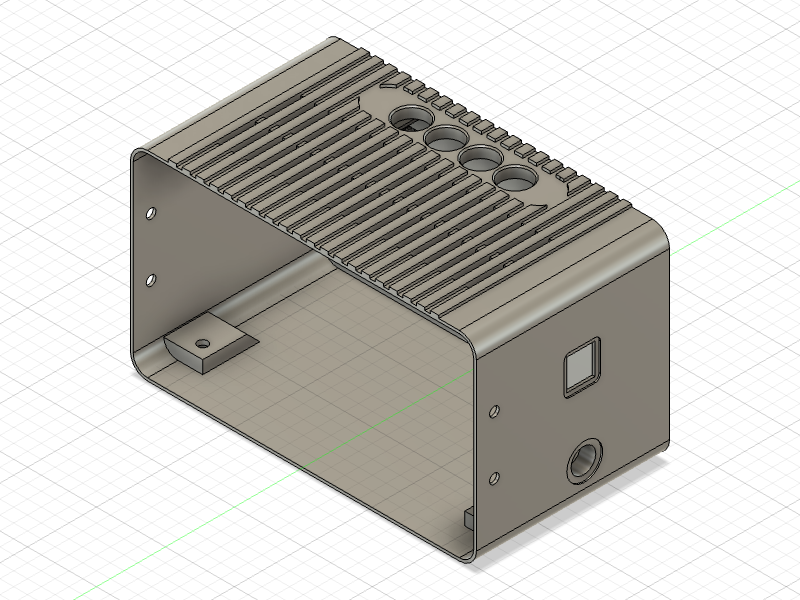
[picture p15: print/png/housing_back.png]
| optional | `./print/stl/housing_back.stl`</BR> | PLA / PETG | In case a housing is required. |
| optional | `./print/stl/housing_front.stl`</BR> | PLA / PETG | In case a housing is required |
| optional: 4 | `./print/png/housing_feet.stl`</BR> | TPU | Only required if housing is required and no standard rubber dampers are used instead, e.g. [AliExpress](https://de.aliexpress.com/item/1005008240903321.html) |
| 1 | `./print/stl/paper_guide_back.stl`</BR> | PLA / PETG |  |
| 1 | `./print/stl/paper_guide_front.stl`</BR> | PLA / PETG |  |
| 1 | `./print/stl/paper_bail_lever.stl`</BR> | PLA / PETG |  |
| 1 | `./print/stl/paper_bail_pusher_front.stl`</BR> | PLA / PETG |  |
| 1 | `./print/stl/paper_bail_pusher_back.stl`</BR> | PLA / PETG |  |
| 2 | `./print/stl/paper_bail_roll_fork.stl`</BR> | PLA / PETG |  |
| 2 | `./print/stl/paper_bail_roll_holder.stl`</BR> | PLA / PETG |  |
| optional | `./print/stl/shaft_connector_flange.stl`</BR> | PLA / PETG | Only required if standard couplers are not used. |
| 1 | `./print/stl/shaft_end_flange.stl`</BR> | PLA / PETG |  |
| 1 | `./print/stl/solenoid_slider.stl`</BR> | PLA / PETG | If a pull solenoid is used. |
| optional | `./print/stl/pcb_holder.stl`</BR> | PLA / PETG |  |
| optional | `./print/stl/cable_management.stl`</BR> | PLA / PETG | Print as needed |

## Mechanical hardware 

| Quantity | Part | Notes |
| --- | ---- | ----- |
| 1 | Pull Solenoid 12V TAU-0530 | [AliExpress](https://de.aliexpress.com/item/32748229525.html) |
| 2 | Stepper Motor NEMA 17 | Square body recommended, e.g. McMaster Carr Part No: 6627T64 |
| 3 | 12mm square rod aluminium/steel | Minimum length for A4: 250 mm without housing, 380 mm with housing. |
| 2 | 6mm round rod aluminium/steel | Minimum length for A4: 250 mm. |
| 3 | 12mm steel shaft | Minimum length for A4: 250 mm. |
| 2 | Linear ball Bearing (6mm ID, 12mm OD, 19mm length) | example McMaster Carr Part No: 3766n13 |
| optional: 1 | 5mm/12mm shaft diameter couplings | Alternatively use printed version |
| 7 | F624ZZ flanged bearings (4mm ID, 13mm OD) | example McMaster Carr Part No: 57155K563 |
| 1 | Compression spring, >=10 mm Long, 7-9 mm OD | McMaster Carr Part No: 94125K203 |
| 1 | Extension Spring with Loop Ends 30mm idle / >=50mm extended | example McMaster Carr Part No: 8464n179 |
| 2 | Extension Spring with Loop Ends 17mm idle / >=25mm extended | example McMaster Carr Part No: 5108N951 |
| optional: 4 | Rubber foam dampers | Optional; can also be 3D-printed. [AliExpress](https://de.aliexpress.com/item/1005008240903321.html) |
| 1 | 5mm 2GT Timing Belt Pulley | example McMaster Carr Part No: 3684N12 |
| 1 | 5mm 2GT Timing Belt | e.g. aliexpress.com/item/1005006322039198.html |
| 1 | 5mm 2GT Timing Belt Idler Pulley | example McMaster Carr Part No: 3693N11 | 

### Fasteners and small hardware

| Quantity | Part | Notes |
| --- | ---- | ----- |
| 1 | M2 x 12 hex socket screw (DIN EN ISO 4762) | For solenoid pin |
| 1 | M2 x 0.4 hex nut (DIN 439-2) | For solenoid pin |
| 6 | M3 x 4 hex socket screws (DIN EN ISO 4762) | for optical endstops and solenoid |
| 36 | M3 x 6 hex socket screws (DIN EN ISO 4762) | general assembly unless otherwise specified |
| 4 | M3 x 20 hex socket screws (DIN EN ISO 4762) | For shaft stepper |
| 4 | M3 x 16 hex socket screws (DIN EN ISO 4762) | For tension springs in rollers |
| 12 | M3 x 0.6 hex nuts (DIN 439-2) | Press into into printed part to counter screws where indicated |
| 1 | M4 x 16 threaded pin (DIN EN ISO 4027) | For timing belt idler |

## Electronics (high-level)

| Quantity | Part | Notes |
| --- | ---- | ----- |
| 1 | Arduino Uno |  |
| 1 | Arduino Uno CNC Shield incl. 2 Stepper Drivers (DRV8825, A4988, or similar) |  |
| 1 | 12V Power supply, 5.5 x 2.1mm | e.g. aliexpress.com/item/32874871456.html |
| 1 | TZT1 MOSFET Driver | drives solenoid, e.g. aliexpress.com/item/32803005422.html |
| 1 | 4 pushbutton module | aliexpress.com/item/1005007272677522.html |
| 2 | Optical endstop | e.g. aliexpress.com/item/1005006173344380.html |

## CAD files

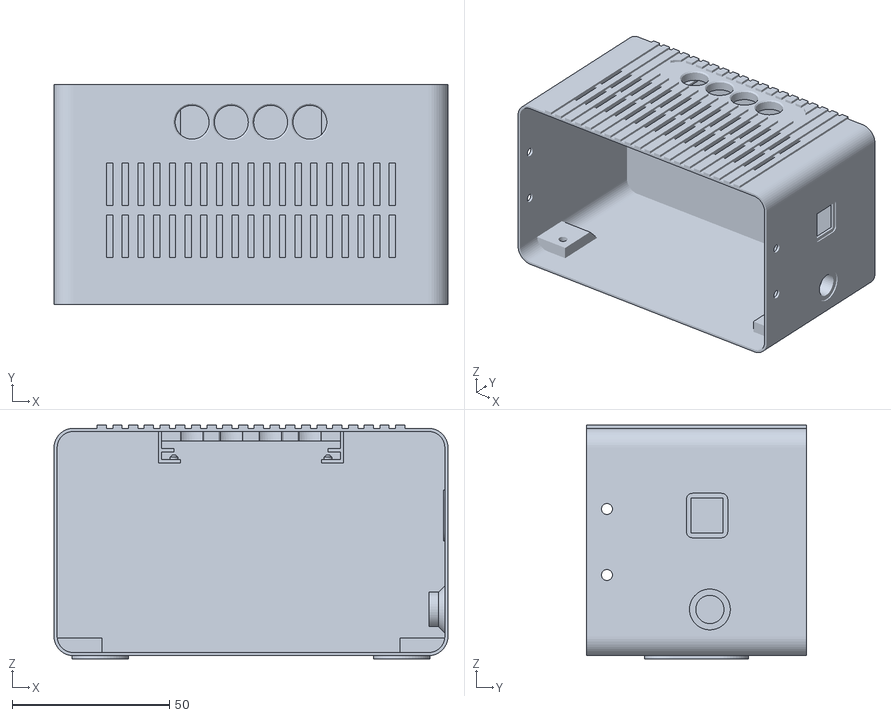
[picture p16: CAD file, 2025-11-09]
print/stl/housing_back.stl
125.4 x 70.0 x 74.4

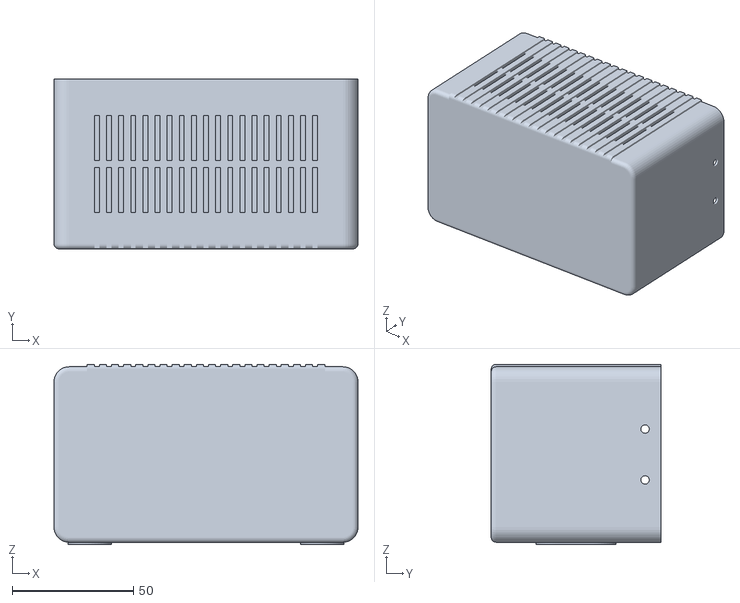
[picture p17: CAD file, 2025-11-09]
print/stl/housing_front.stl
125.4 x 70.0 x 74.4

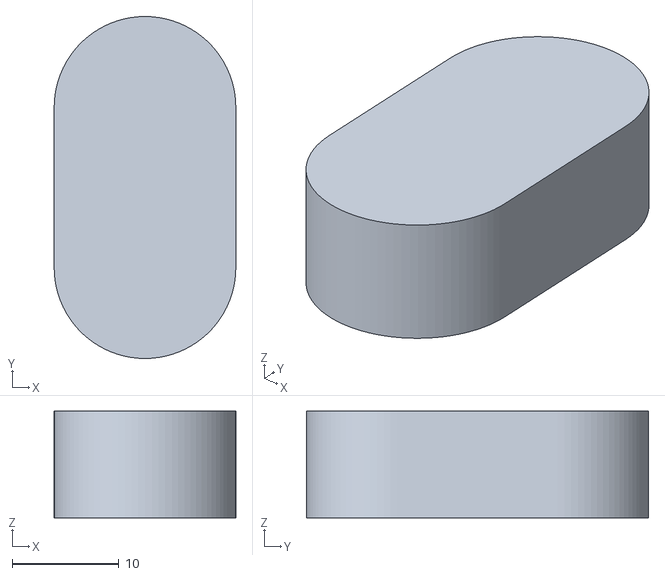
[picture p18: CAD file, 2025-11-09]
print/stl/housing_feet.stl
17.0 x 32.0 x 10.00

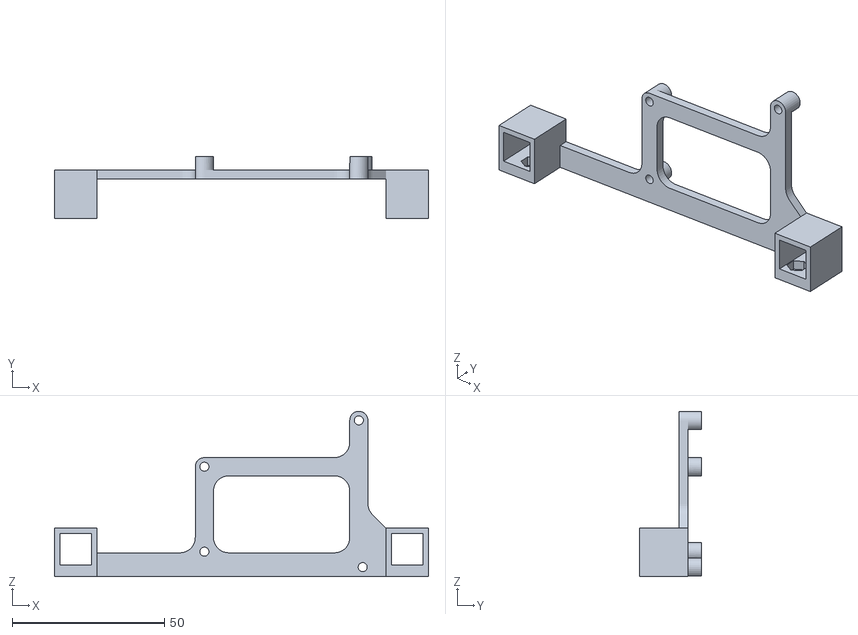
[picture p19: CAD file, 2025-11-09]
print/stl/pcb_holder.stl
123.0 x 20.4 x 54.4

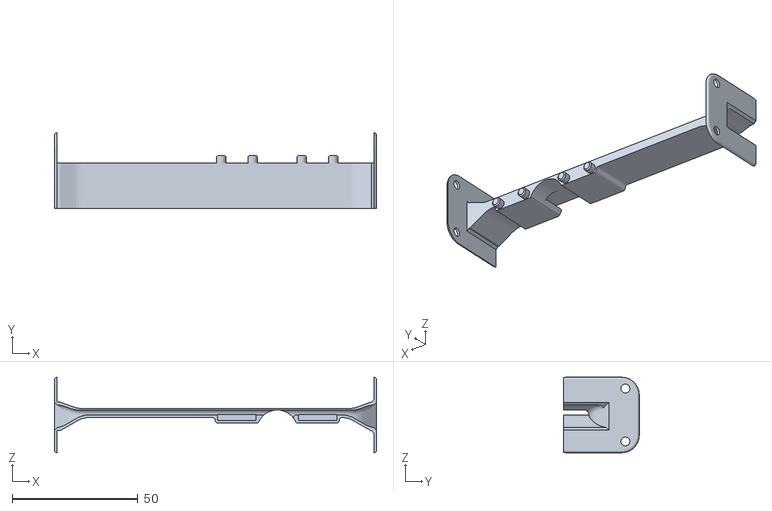
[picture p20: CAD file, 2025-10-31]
print/stl/paper_guide_back.stl
127.8 x 30.0 x 30.0

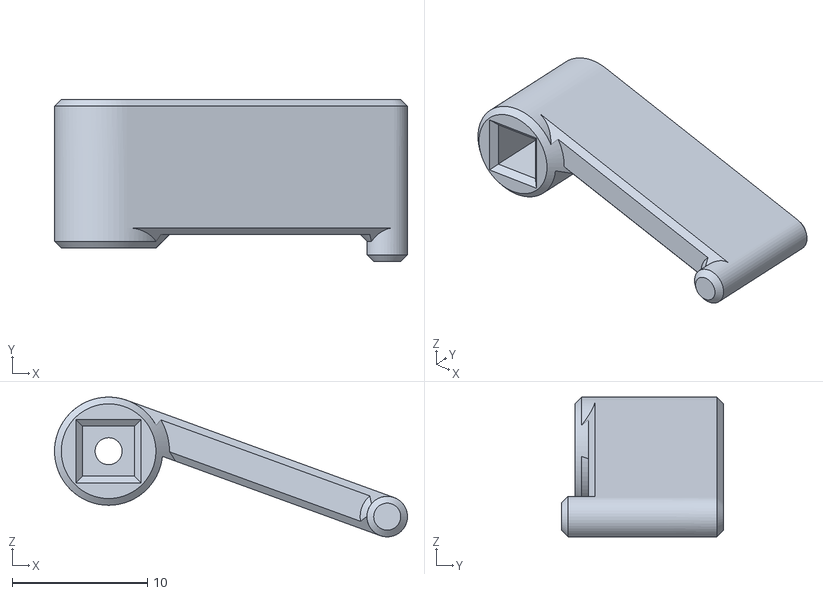
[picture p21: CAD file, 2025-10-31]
print/stl/flat_steel_lever.stl
26.1 x 12.0 x 10.3

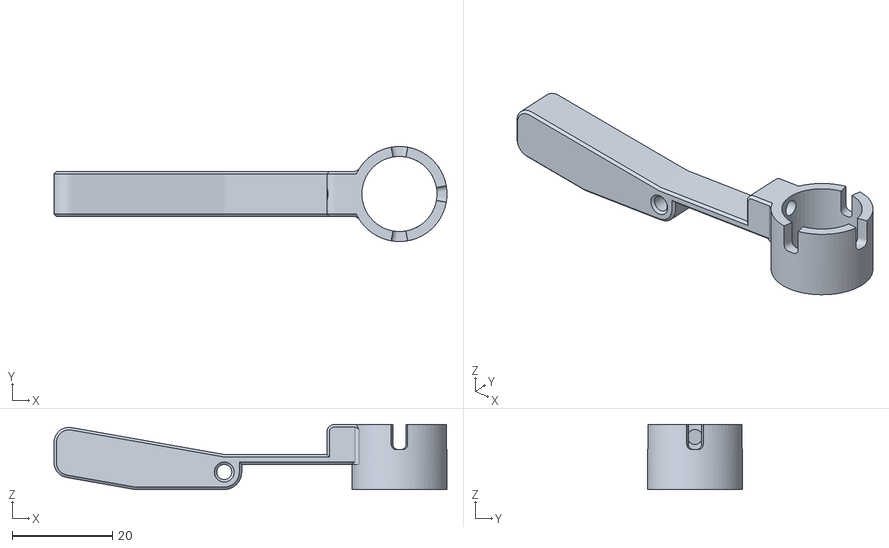
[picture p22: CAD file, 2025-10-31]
print/stl/carriage_penholder_base.stl
78.5 x 19.0 x 13.0

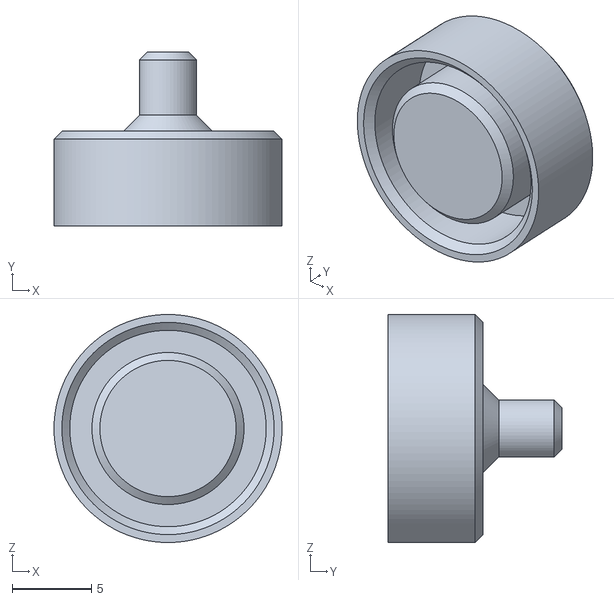
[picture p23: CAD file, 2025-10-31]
print/stl/shaft_end_flange.stl
14.4 x 11.0 x 14.4

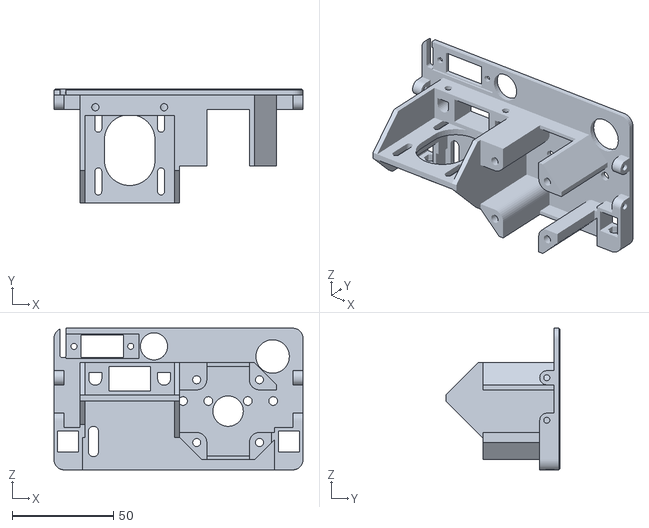
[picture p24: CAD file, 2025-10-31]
print/stl/frame_front.stl
123.0 x 56.3 x 70.0

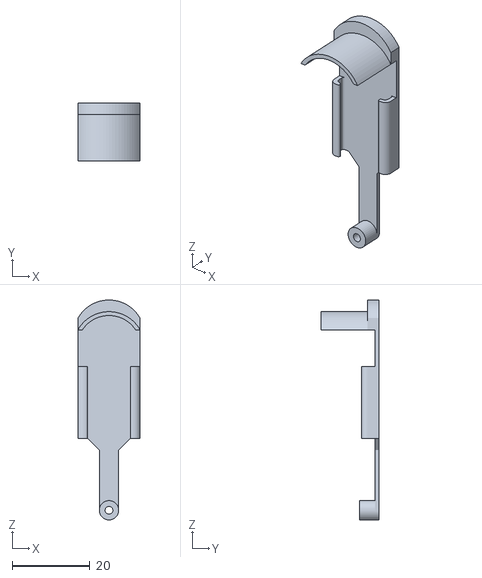
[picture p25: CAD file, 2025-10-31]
print/stl/solenoid_slider.stl
16.0 x 15.0 x 56.7

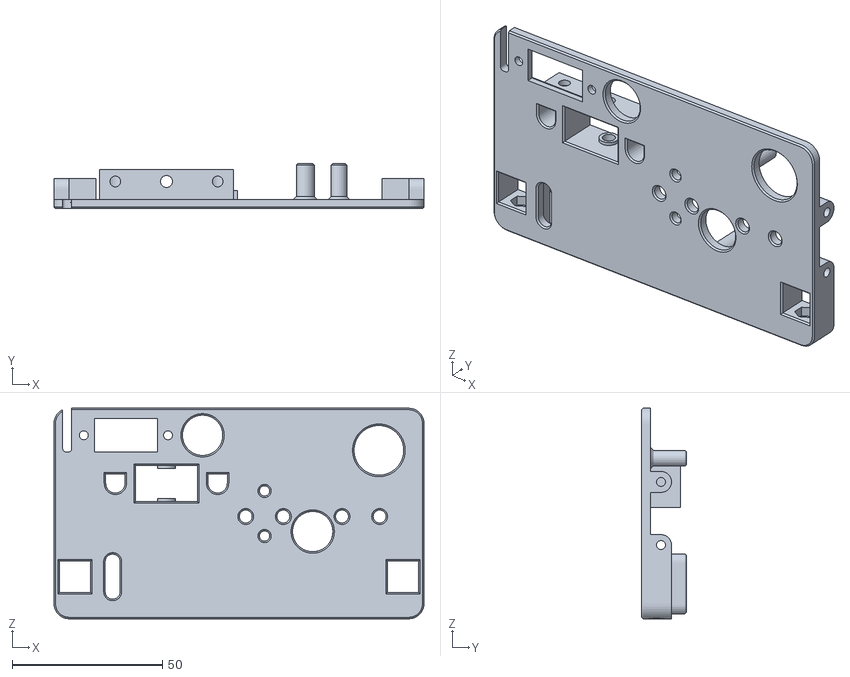
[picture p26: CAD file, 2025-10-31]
print/stl/frame_back.stl
123.0 x 15.0 x 70.0

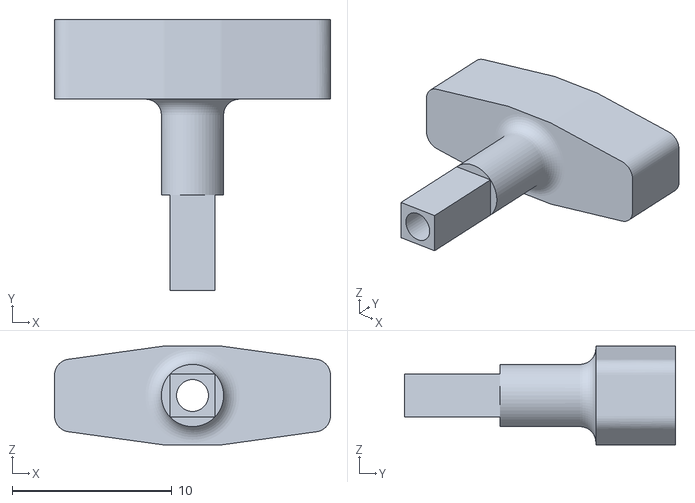
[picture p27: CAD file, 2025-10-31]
print/stl/flat_steel_flange.stl
17.3 x 17.0 x 6.20

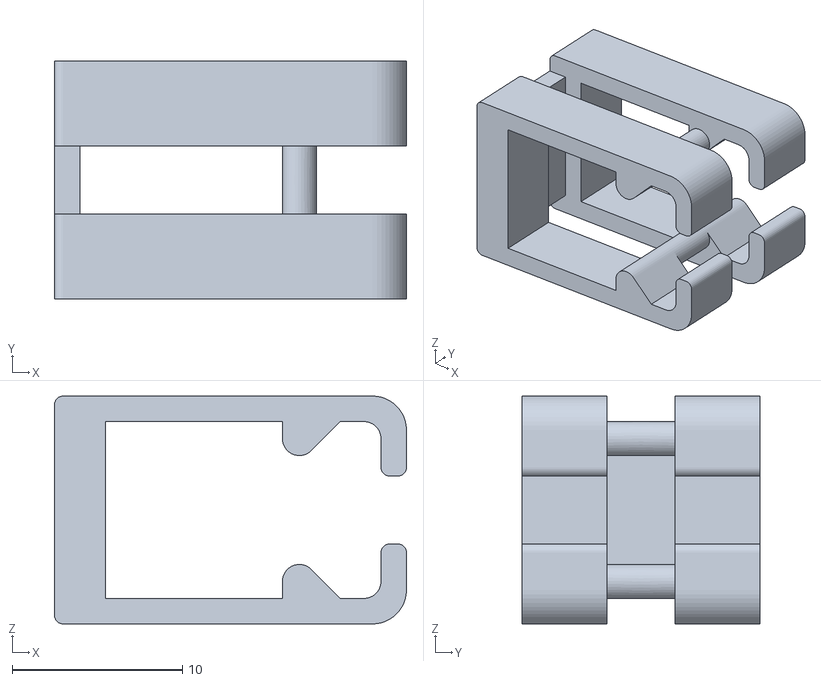
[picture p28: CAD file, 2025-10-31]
print/stl/cable_management.stl
20.7 x 14.0 x 13.4

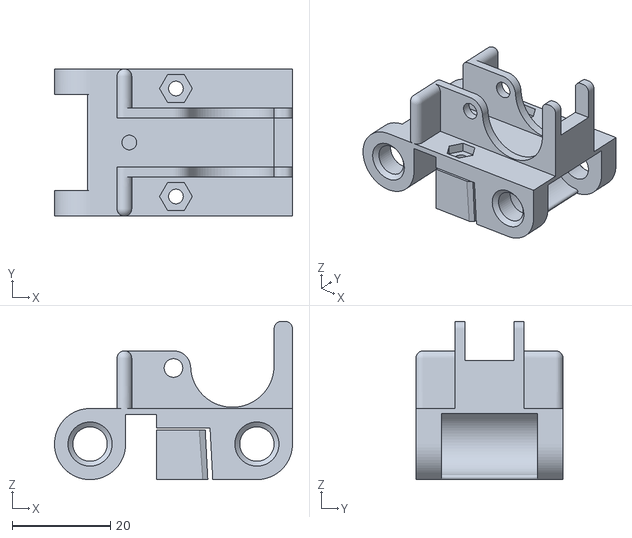
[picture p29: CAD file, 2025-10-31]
print/stl/carriage.stl
48.5 x 30.0 x 32.2

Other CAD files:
print/stl/paper_guide_front.stl
print/stl/shaft_connector_flange.stl
print/stl/paper_bail_lever.stl
print/stl/paper_bail_pusher_back.stl
print/stl/carriage_penholder_connector_screw.stl
print/stl/paper_bail_pusher_front.stl
print/stl/paper_bail_roll.stl
print/stl/paper_bail_roll_fork.stl
print/stl/paper_bail_roll_holder.stl

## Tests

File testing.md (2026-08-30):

# Test & Commissioning Guide

> ⚠️ **Work in progress.** Some steps below still contain known contradictions
> and stale references, marked inline with `TODO:` and tracked in
> [TODO.md](TODO.md). Read those markers before relying on the affected step.

**This document is the single source for the whole test and commissioning
sequence.** Other files (`README.md`, `firmware/README.md`, `electronics.md`,
`pipeline/README.md`) only link here — they do not repeat the procedure.

The sequence is split into phases:

| Phase | What is tested | TCs | Purpose |
|---|---|-----|---|
| [Phase 0](#phase-0--prerequisites) | Assembly, wiring, software install | — | Bring the machine and host into a testable state |
| [Phase 1](#phase-1--standalone-arduino-tests-no-grbl) | Standalone Arduino sketch per TC | TC1–TC4 | Test individual hardware components directly, no GRBL involved |
| [Phase 2](#phase-2--grbl-integration-tests) | GRBL (production firmware) | TC5-G–TC9-G | Verify the full hardware system through GRBL and G-code |
| [Phase 3](#phase-3--pipeline-software-tests) | Host-side Python pipeline | TC-P1–TC-P3 | Verify the image-processing and G-code generation pipeline |
| [Phase 4](#phase-4--full-system-end-to-end-plot) | Complete system (host + plotter) | TC-E1–TC-E3 | Run a real pipeline and send the output to the connected plotter |

Run the phases in order:

- Phase 1 first — fastest to flash, easiest to debug individual hardware signals.
- Phase 2 only after all Phase 1 tests pass.
- Phase 3 runs independently on the host PC and does **not** require the plotter to be connected.
- Phase 4 requires both Phase 2 (hardware verified) and Phase 3 (pipeline verified) to have passed.

---

## Phase 0 — Prerequisites

**Mechanics & electronics**

1. Frame printed and assembled — see [README.md → Assembly](README.md#assembly).
2. Electronics wired — see [electronics.md → Wiring steps](electronics.md#wiring-steps).
3. 12 V power supply connected to the CNC Shield screw terminals; USB cable to the Arduino.
4. PlatformIO installed (`pio` CLI or the VS Code extension).
5. A serial monitor ready (`pio device monitor`, or any 115200-baud terminal).

**Host software** (only needed from Phase 3 onward)

6. Python **3.13** (not 3.14 — `vpype` requires `<3.14`) and the project
   virtualenv installed — see
   [pipeline/README.md → Installation](pipeline/README.md#installation).

**GRBL settings** (only needed from Phase 2 onward)

7. After flashing GRBL, walk through the first-run parameter checklist and
   verify with `$$` — see
   [firmware/README.md → Key GRBL settings](firmware/README.md#key-grbl-settings-first-run-checklist).

---

## Phase 1 — Standalone Arduino Tests (no GRBL)

Each test is a self-contained Arduino sketch.  
Flash it, open the serial monitor at **115200 baud**, and follow the on-screen prompts.  
The sketch guides you through each step and prints `PASS` or `FAIL` at the end.

```
firmware/
└── test/
    ├── tc1_x_axis/     tc1_x_axis.cpp
    ├── tc2_endstops/   tc2_endstops.cpp
    ├── tc3_y_axis/     tc3_y_axis.cpp
    └── tc4_pen_lift/   tc4_pen_lift.cpp
```

Flash command pattern:

```bash
cd firmware
pio run -e <env_name> -t upload
pio device monitor
```

---

### TC1 — X-Axis Movement

**Goal:** Verify that the X stepper (carriage) moves and that the direction mapping is correct.

**Flash:**

```bash
pio run -e tc1_x_axis -t upload
```

**What the sketch does:**

| Step | Action | Expected |
|---|---|---|
| 1 | Prompts operator to centre the carriage | — |
| 2 | Moves X axis RIGHT (DIR=HIGH), 25 steps (~5 mm) | Carriage moves right |
| 3 | Asks: "Did the carriage move RIGHT?" | Operator confirms |
| 4 | Moves X axis LEFT (DIR=LOW), 800 steps (~10 mm) | Carriage moves left past centre |
| 5 | Asks: "Did the carriage move LEFT?" | Operator confirms |
| 6 | Prints PASS / FAIL | — |

**Failure hints:**

| Symptom | Likely cause | Fix |
|---|---|-----|
| Wrong motor moves | X/Y motor cables swapped | Swap X and Y connectors on CNC Shield |
| Both directions reversed | DIR sense wrong | Flip the DIR level in the sketch; under GRBL later, set `$3=1` (invert X) |
| Motor buzzes, no movement | Current limit too low or motor coil pairs swapped | Re-adjust A4988 trimmer; check motor wiring order |

---

### TC2 — Endstops

The machine has **two optical endstops, both on the X axis** (X_MIN + X_MAX),
wired in parallel onto the single `X_LIMIT` pin (D9). None on Y. See
[electronics.md → Machine configuration](electronics.md#machine-configuration-canonical).
The sketch cannot tell the two switches apart (neither can GRBL) — you
confirm which physical end was reached.

**Goal:** Both X switches trigger `X_LIMIT` at the correct ends and in the correct sense.

**Flash:**

```bash
pio run -e tc2_endstops -t upload
```

**What the sketch does:**

| Step | Action | Expected |
|---|---|---|
| 1 | Prompts operator to centre the carriage; checks `X_LIMIT` (D9) | Reads HIGH (open) |
| 2 | Drives slowly toward X_MIN until D9 goes active; stops; backs off | Stops at front/left end |
| 3 | Asks: "stopped at the FRONT/LEFT end (X_MIN)?" | Operator confirms |
| 4 | Drives slowly toward X_MAX until D9 goes active; stops; backs off | Stops at back/right end |
| 5 | Asks: "stopped at the BACK/RIGHT end (X_MAX)?" | Operator confirms |
| 6 | Prints PASS / FAIL | — |

**Endstop logic:** the sketch reads the raw pin (LOW = beam blocked). Under
GRBL this is governed by `$5` — see the TODO in
[electronics.md → Endstops](electronics.md#endstops).

**Failure hints:**

| Symptom | Likely cause | Fix |
|---|---|-----|
| `X_LIMIT` reads active at idle | A switch is blocked, wiring shorted, or module polarity inverted | Check placement/wiring; if idle is genuinely LOW, invert `TRIGGERED_LEVEL` in the sketch and set `$5` the other way |
| Limit never fires at an end | No 5 V on the header, signal wire missing, or that switch not in the beam path | Check the 3-pin connector (GND/5V/SIG); adjust the switch mount |
| One end works, the other doesn't | Only one of the two switch signals reaches D9 | Check how the two outputs are combined onto the X- pin (diode-OR / wired-OR) |
| Direction reversed (hits X_MAX when driving toward X_MIN) | X DIR sense inverted | Flip the DIR level in the sketch; under GRBL set `$3=1` |

---

### TC3 — Y-Axis Movement

**Goal:** Verify that the Y stepper (paper feed) moves and that paper is fed in the correct direction.

**Flash:**

```bash
pio run -e tc3_y_axis -t upload
```

**What the sketch does:**

| Step | Action | Expected |
|---|---|---|
| 1 | Prompts operator to insert a sheet of paper into the paper bail | — |
| 2 | Drives Y axis IN (DIR=HIGH), 100 steps (~20 mm) | Paper pulled into plotter |
| 3 | Asks: "Was paper pulled IN?" | Operator confirms |
| 4 | Drives Y axis OUT (DIR=LOW), 100 steps (~20 mm) | Paper ejected |
| 5 | Asks: "Was paper pushed OUT?" | Operator confirms |
| 6 | Prints PASS / FAIL | — |

**Failure hints:**

| Symptom | Likely cause | Fix |
|---|---|-----|
| Carriage moves instead of paper feed | X/Y motor cables swapped | Swap X and Y connectors on CNC Shield |
| Both directions reversed | DIR sense wrong | Flip the DIR level in the sketch; under GRBL later, set `$3=2` (invert Y) |
| Motor turns but paper doesn't move | Feed roller not gripping | Check roller tension spring and bail assembly |

---

### TC4 — Pen Lift (Solenoid)

**Goal:** Verify the solenoid fires on command and the pen returns via spring on release.

**Flash:**

```bash
pio run -e tc4_pen_lift -t upload
```

**What the sketch does:**

| Step | Action | Expected |
|---|---|---|
| 1 | Prompts operator to confirm flyback diode and 12 V supply | — |
| 2–5 | Cycles solenoid 4 times: 1 s ON → 3 s OFF (cool-down) | Audible click + visible pen drop each cycle; pen returns up each time |
| 6 | Asks: "Did solenoid actuate on all cycles?" | Operator confirms |
| 7 | Asks: "Did pen return UP after each cycle?" | Operator confirms |
| 8 | Prints PASS / FAIL | — |

> ⚠️ **Safety:** Do not energise the solenoid continuously for more than ~2 s.  
> The 3 s cool-down between cycles is the minimum recommended interval.

**Failure hints:**

| Symptom | Likely cause | Fix |
|---|---|-----|
| No actuation at all | MOSFET gate not reaching D11; no 12 V supply | Check D11 wiring to MOSFET gate; check 12 V rail |
| Weak / incomplete stroke | MOSFET Vgs threshold too high; 12 V insufficient | Use a logic-level MOSFET (IRLZ44N); check PSU voltage under load |
| Pen does not return | Return spring missing or too weak | Check / replace return spring; verify solenoid slider moves freely |
| MOSFET gets very hot | Flyback diode missing | Install 1N4007 across solenoid coil immediately |

---

## Phase 2 — GRBL Integration Tests

Flash GRBL (production firmware) and control the plotter via G-code from a PC.  
The same four functions are tested, this time through the full GRBL stack.

### 2.0 — Flash GRBL and connect

```bash
cd firmware
pio run -e uno -t upload
pio device monitor            # 115200 baud
```

After reset you should see:

```
Grbl 1.1h ['$' for help]
[MSG:Caution: Unlocked]
```

If GRBL shows `ALARM:` on startup, homing is required first (see TC5-G below).

**Recommended G-code sender:** [UGS (Universal G-code Sender)](https://universalgcodesender.com/)  
Connect at **115200 baud**. Use the MDI (Manual Data Input) console to send commands.

---

### TC5-G — Initialisation and Homing

**Goal:** GRBL starts cleanly and the homing cycle completes without errors.

**Procedure:**

```gcode
$H
```

Only the **X axis** homes (`HOMING_CYCLE_0 = X`). Y has no endstop and is not
homed; Z is disabled.

**Expected sequence:**

1. Carriage accelerates toward X_MIN.
2. Slows down and touches X_MIN.
3. Backs off by `$27` (5 mm pull-off).
4. GRBL responds with `ok`; machine position X is set to 0. (Y stays at its
   power-up value — Y is not homed.)

| Response | Meaning |
|---|---|
| `ok` | Homing successful |
| `ALARM:8` | Endstop not reached within travel limit — check endstop wiring |
| `ALARM:9` | Endstop still triggered after pull-off — check sensor alignment |

After this, run **TC5b-G** to measure and store the X-axis length.

---

### TC5b-G — Teach the X-axis length

GRBL homes X against X_MIN only. X_MAX shares the same limit pin, so its
position must be measured once and stored in `$130`.

```gcode
$21=1                 ; enable hard limits so X_MAX stops the jog
$H                    ; home to X_MIN → machine X = 0
```

Then jog toward X_MAX in small steps until GRBL raises `ALARM:1`:

```gcode
$J=G91 X20 F500       ; repeat until ALARM:1 (X_MAX reached)
```

```gcode
?                     ; note the last MPos:X before the alarm = usable X length
$X                    ; clear the alarm
$130=<that value minus ~3 mm>   ; store X max travel
$20=1                 ; enable soft limits — moves are now bounded
```

Re-run whenever the belt, pulleys or switch positions change. For steps/mm,
direction, acceleration and squaring, see
[firmware/GRBL.md → Calibration](firmware/GRBL.md#calibration).

| Symptom | Likely cause | Fix |
|---|---|-----|
| No `ALARM:1` at the far end | X_MAX not wired to `X_LIMIT` (D9), or `$21=0` | Check both X switches share D9; set `$21=1` |
| `ALARM:1` immediately on `$H` | X_MAX (or X_MIN) stuck triggered, or `$5` inverted | Check optical alignment; verify `$5` (see TODO.md) |

---

### TC6-G — Endstop Signals in Idle State

**Goal:** Confirm both X endstops read as open when the carriage is clear, and that each one is seen by GRBL.

Both X switches sit on the `X_LIMIT` pin, so GRBL reports **`Pn:X` for either
one** — it cannot tell them apart. There is no `Pn:Y` (Y has no endstop).

**Step 1 — Status check with carriage in the middle:**

```gcode
$X
?
```

The `Pn:` field must be **absent** (no limit flags):

```
<Idle|MPos:0.000,0.000,0.000|FS:0,0>
```

**Step 2 — Trigger X_MIN by hand:**  
Block the X_MIN optical sensor with a finger, then send `?`.  
Expected: status contains `Pn:X`. Unblock — confirm `Pn:X` disappears.

**Step 3 — Trigger X_MAX by hand:**  
Block the X_MAX optical sensor — confirm `Pn:X` appears again (same flag as
X_MIN), then disappears when released.

| Observation | Meaning |
|---|---|
| `Pn:X` only when expected | Endstop wiring correct |
| `Pn:X` always present | Sensor permanently triggered or signal wire shorted |
| `Pn:X` never appears | No 5 V on header, broken signal wire, or sensor faulty |

---

### TC7-G — X-Axis Movement via GRBL

**Goal:** Verify GRBL moves the X axis the correct distance in each direction.

**Procedure:**

```gcode
$X                  ; clear alarm lock (if present)
G91                 ; relative positioning mode
G1 X5 F500          ; move X +5 mm (carriage should move RIGHT)
```

> Confirm: carriage moved right ~5 mm.

```gcode
G1 X-10 F500        ; move X -10 mm (carriage should move LEFT, past start)
G90                 ; back to absolute positioning
```

> Confirm: carriage moved left ~10 mm.

**Step — Drive to X_MIN with hard limits:**

```gcode
$21=1
G91
G1 X-200 F800
```

> Expected: GRBL stops when X_MIN triggers and raises `ALARM:1`.  
> The carriage must **not** crash into the mechanical stop.

```gcode
$21=0
$X
G90
```

**Failure hints:**

| Symptom | Likely cause | Fix |
|---|---|-----|
| Wrong motor moves | X/Y motor cables swapped | Swap connectors on CNC Shield |
| Both directions reversed | Direction invert wrong | Send `$3=1` (invert X) |
| Carriage crashes through endstop | Hard limit not wired / `$21` not set | Check endstop wiring; set `$21=1` |

---

### TC8-G — Y-Axis Movement via GRBL

**Goal:** Verify GRBL feeds paper correctly in both directions.

Y has no endstop and is never homed — GRBL treats the current position as
`Y = 0`. Insert a sheet of paper into the paper bail first; that position is
your origin. If soft limits are on (`$20=1`), a `Y-` move past 0 is refused,
so send `G92 Y0` after loading paper if you need headroom for the OUT move.

```gcode
$X                  ; clear alarm
G91                 ; relative mode
G1 Y30 F500         ; feed paper IN 30 mm
```

> Confirm: paper is pulled into the plotter.

```gcode
G1 Y-30 F500        ; feed paper OUT 30 mm
G90
```

> Confirm: paper is ejected.

**Failure hints:**

| Symptom | Likely cause | Fix |
|---|---|-----|
| Carriage moves instead of paper | X/Y motor cables swapped | Swap connectors |
| Both directions reversed | Direction invert wrong | Send `$3=2` (invert Y) |
| Motor turns, paper doesn't move | Roller not gripping | Check roller tension |

---

### TC9-G — Pen Lift via GRBL (1 s down, then up)

**Goal:** Verify GRBL controls the solenoid via M3/M5 spindle commands with correct timing.

> ⚠️ Same solenoid safety rules apply: do not energise continuously for more than ~2 s.

> **TODO** ([TODO.md](TODO.md)): confirm the M3/M5 mapping against the
> assembled hardware and `pipeline/configs/grbl_a4_pen.toml` — this guide
> assumes inverted wiring (`M3 S1000` = energised = pen **UP**, `M5` = pen
> **DOWN** via spring).

```gcode
M5                  ; solenoid OFF → pen DOWN (spring return)
G4 P1               ; dwell 1 second
M3 S1000            ; solenoid ON  → pen UP (lift)
```

> Confirm: solenoid clicks and pen moves DOWN on `M5`, pen returns UP after `G4 P1` + `M3`.

Repeat three more times with cool-down pauses:

```gcode
G4 P3
M5
G4 P1
M3 S1000
G4 P3
M5
G4 P1
M3 S1000
G4 P3
M5
G4 P1
M3 S1000
```

**Failure hints:**

| Symptom | Likely cause | Fix |
|---|---|-----|
| Solenoid does not fire | Spindle settings wrong | Check `$30=1000` and `$31=0` via `$$` |
| Solenoid fires but pen doesn't move | Mechanical binding | Check solenoid slider moves freely |
| Pen does not return | Return spring missing or weak | Check / replace return spring |
| MOSFET very hot | Flyback diode missing | Install 1N4007 across solenoid coil immediately |

---

## Phase 3 — Pipeline Software Tests

This phase verifies the host-side Python pipeline that converts images to G-code.  
It runs entirely on the host PC — **no plotter connection is required**.

### Phase 3 Prerequisites

- Python **3.13** (not 3.14 — `vpype` requires `<3.14`) and the project
  virtualenv set up — see
  [pipeline/README.md → Installation](pipeline/README.md#installation)
  (`python3.13 -m venv .venv && .venv/bin/pip install -e "pipeline/[gui]"`).

- All hardware tests (Phase 1 + Phase 2) should have passed before an end-to-end plot is attempted, but Phase 3 can be run independently at any time.

The test image used throughout Phase 3 & 4 is `pipeline/input/testimage.png`.

Two configs are used below:
- `pipeline/examples/standard_pipeline.yaml` — offline: image → sketch →
  vectorize → **G-code file** (Phase 3).
- `pipeline/configs/plotter.yaml` — image → vectorize → G-code → **serial
  stream to GRBL** (Phase 4). Set its `port:` for your machine.

---

### TC-P1 — Unit Tests

**Goal:** All pipeline unit tests pass without errors.

**Run:**

```bash
.venv/bin/pytest pipeline/tests/ -v
```

**Expected:** every test in `pipeline/tests/test_*.py` shows `PASSED`; no
`FAILED` or `ERROR` entries. (Don't check against a fixed count — the suite
grows.)

**Failure hints:**

| Symptom | Likely cause | Fix |
|---|---|-----|
| `ModuleNotFoundError` | Virtualenv not activated or incomplete install | `.venv/bin/pip install -e "pipeline/[gui]"` |
| `ImportError: cannot import name ...` | Outdated installed package | `.venv/bin/pip install -e "pipeline/[gui]" --upgrade` |
| Individual test `FAILED` | Step logic regression | Check the failing test and the corresponding step in `pipeline/steps/` |

---

### TC-P2 — Pipeline Config Smoke Tests

**Goal:** The sample pipeline YAML configs execute without Python errors on the test image.

**Run:**

```bash
.venv/bin/python pipeline/tests/run_all_pipeline_configs.py          # all configs
.venv/bin/python pipeline/tests/run_all_pipeline_configs.py --fast   # CPU-only, no downloads
```

**What this does:**

Each `*.yaml` under `pipeline/tests/pipeline_configs/` is loaded via
`PipelineRunner.from_yaml` and executed against `pipeline/input/testimage.png`.
Every step must complete without raising. Configs whose optional dependency is
missing (e.g. `diffusers`) are reported as *skipped*, not failed.

**Expected:** every config reports `OK` (or `~` skipped), none `X`:

```text
  [stylize_adaptive    ]  ... OK   ...
  [stylize_canny       ]  ... OK   ...
  [stylize_controlnet  ]  ... ~    skipped (missing dependency: ...)
  ...
  Results: N ok  M skipped  0 errors
```

> ⚠️ Without `--fast`, the NN configs (`stylize_hed`, `stylize_dexined`,
> `stylize_lineart`, `stylize_informative`) download model weights on first
> run (~0.1–0.4 GB each); the diffusion configs (`stylize_controlnet`,
> `stylize_img2img`) need the `[diffusers]` extra and are skipped without it.
> Use `--fast` for a quick check that needs no network.

**Failure hints:**

| Symptom | Likely cause | Fix |
|---|---|-----|
| `Step not found in registry` | Step name typo or missing registry entry | Check `pipeline/core/registry.py` |
| `FileNotFoundError: testimage.png` | Test image missing | Confirm `pipeline/input/testimage.png` exists |
| NN model download fails | No internet / HuggingFace token required | Run `.venv/bin/get-hf-token` |

---

### TC-P3 — End-to-End G-code Generation

**Goal:** The full offline pipeline (sketch → vectorize → G-code) produces a valid `.gcode` file for a real input image.

**Run:**

```bash
.venv/bin/pipeline-run \
    --config pipeline/examples/standard_pipeline.yaml \
    --input  pipeline/input/testimage.png \
    --output /tmp/test_output.gcode \
    --verbose
```

**Expected:**

1. Pipeline runs without errors; the log ends with `Pipeline completed.`
2. `/tmp/test_output.gcode` is created and non-empty.
3. It is valid G-code: starts with `G21` / `G90`, contains `G1` moves and `M3`/`M5` pen commands, and ends on `M5`.

**Quick validation:**

```bash
head -6 /tmp/test_output.gcode          # G21, G90, G1 F3000, M3 S1000, ...
grep -c "^G1 " /tmp/test_output.gcode   # should be > 0
tail -3 /tmp/test_output.gcode          # should contain a final M5
```

**Failure hints:**

| Symptom | Likely cause | Fix |
|---|---|-----|
| Pipeline aborts with a traceback | A step raised an exception | Re-run with `--verbose` and read the failing step |
| Output file empty / only header+footer | Vectorization produced 0 paths | Lower `min_path_px` / `simplify_eps`, or raise `style_res`, or lower `threshold` in the `stylise_xdog` step |
| `ModuleNotFoundError` | Incomplete install | `.venv/bin/pip install -e "pipeline/[gui]"` |

---

## Phase 4 — Full System End-to-End Plot

This phase tests the complete system: host PC pipeline → USB serial → GRBL plotter.  
A real image is processed by the pipeline and the resulting G-code is streamed live to the connected plotter.

**Prerequisites — all of the following must be true before starting Phase 4:**

- [ ] Phase 1 passed (all hardware components verified)
- [ ] Phase 2 passed (GRBL firmware running, homing and axes verified)
- [ ] Phase 3 passed (pipeline software verified on test image)
- [ ] Plotter connected via USB and recognised by the OS
- [ ] Paper loaded into the paper bail
- [ ] Pen inserted into the carriage

### Phase 4 Prerequisites

**Find your serial port:**

```bash
# macOS
ls /dev/tty.usbmodem*

# Linux
ls /dev/ttyUSB* /dev/ttyACM*

# Windows
# Check Device Manager → Ports (COM & LPT)
```

Then set that port in `pipeline/configs/plotter.yaml` (the `send_gcode`
step's `port:` field). All Phase 4 tests use that config.

---

### TC-E1 — Dry-Run: Pipeline to Serial (no motion)

**Goal:** Verify the pipeline generates G-code and the serial connection to GRBL is established — without any physical motion.

**Step 1 — Put `plotter.yaml` in dry-run mode:**

In `pipeline/configs/plotter.yaml`, set the `send_gcode` step's
`dry_run: true`.

**Step 2 — Run:**

```bash
.venv/bin/pipeline-run \
    --config pipeline/configs/plotter.yaml \
    --input  pipeline/input/testimage.png \
    --verbose
```

**Expected:**

- Pipeline runs through all steps without error.
- Log shows the serial port opened successfully.
- Log shows G-code lines read/validated but **not** sent (`dry_run=true`).
- Plotter does **not** move.

**Failure hints:**

| Symptom | Likely cause | Fix |
|---|---|-----|
| `SerialException: could not open port` | Wrong port or driver missing | Check `ls /dev/tty.usbmodem*`; try replug USB |
| `ALARM:` in log | GRBL not homed | Connect with UGS and run `$H` first |
| Pipeline fails before `send_gcode` | Earlier step error | Fix TC-P2/TC-P3 failures first |

---
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

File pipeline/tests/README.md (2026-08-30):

# pipeline/tests — unit tests and smoke runners

For where these tests fit into bring-up, see
[../../testing.md → Phase 3](../../testing.md#phase-3--pipeline-software-tests).

This directory contains the pytest unit tests (`test_*.py`) plus a set of
pipeline configuration YAMLs (`pipeline_configs/`) used for smoke testing the
pipeline steps. Two helper scripts are provided:

- `run_all_pipeline_configs.py` — runs each `*.yaml` in
  `pipeline/tests/pipeline_configs/` through `PipelineRunner`. `--fast`
  restricts it to the CPU-only configs (no model downloads).
- `run_all_tests.py` — unified runner: pytest for `test_*.py`, then the smoke
  test (`--skip-smoke` / `--fast` / `--pytest-args "..."`).

## Important behavior

The smoke runner intentionally does NOT preload the image into the pipeline
context. Instead it sets only the source path:

```python
ctx = ImageContext(metadata={"source_path": Path("pipeline/input/testimage.png")})
```

This enforces that pipelines are self-contained: a YAML that needs an image
from disk must include a `load_image` step which reads
`metadata['source_path']`. A pipeline that requires a pre-loaded `ctx.image`
must be run by a custom harness that provides it.

## Why

This makes test behavior explicit and prevents silent inconsistencies: the
runner no longer overrides a pipeline's configured behavior by mutating or
pre-loading the image.

## Running tests

Unit tests (fast):

```bash
.venv/bin/pytest pipeline/tests/ -v
```

Config smoke test (`--fast` = CPU-only, no downloads):

```bash
.venv/bin/python pipeline/tests/run_all_pipeline_configs.py --fast
```

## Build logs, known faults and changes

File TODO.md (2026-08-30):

# TODO — known open issues

**Status: the whole project is work in progress.** Hardware wiring, firmware
configuration and the software pipeline are still changing, and several docs
have drifted apart during past refactors. This file is the single list of
known contradictions and errors that still need to be resolved.

Inline `TODO:` markers throughout the docs point back here.

---

## Hardware / firmware

The machine layout is now settled and captured in
[electronics.md → Machine configuration](electronics.md#machine-configuration-canonical):
**2 optical endstops both on X (X_MIN + X_MAX) on D9, no Y endstop, X-only
homing, solenoid on D11 via `VARIABLE_SPINDLE`.** `config.h`, `electronics.md`,
`testing.md` and `firmware/README.md` were updated to match, and
`firmware/src/config.h` is now actually wired into the build (`-include`;
it overrides `HOMING_CYCLE_0` and asserts `VARIABLE_SPINDLE`, machine
params via `$`). Remaining:

- [ ] **Optical-endstop polarity / `$5` is unverified.** In GRBL 1.1,
  `$5=1` → "pin HIGH = triggered", `$5=0` → "pin LOW = triggered". Measure
  the real module output (beam clear vs. blocked) and set `$5` on the board.
  Also confirm the two parallel X switches can share D9 without an output
  clash (open-collector / wired-OR).
- [ ] **Tune the solenoid holding current.** `grbl_a4_pen.toml` now pulls the
  pen up at `S1000` then holds at `S350` (~35 % PWM). Find the lowest hold
  value that reliably keeps the pen up during travel, and check the coil is
  no more than warm after a long plot. Update `S_HOLD` in both
  `document_start` and `line_end`.
- [ ] **`$130` (X max travel) must be taught** — testing.md TC5b-G. Verify the
  teach procedure (home X_MIN, jog to X_MAX, read MPos) works on the hardware.
- [ ] **Verify homing + solenoid on the real board** now that `config.h` is
  wired in: `$H` homes X only (no Z/Y move), `M3`/`M5` drive the pen on D11.
- [ ] **`testing.md` TC9-G M3/M5 order** — `M5` (pen down) → dwell → `M3 S1000`
  (pen up). Confirm against the assembled hardware.
- [ ] **GRBL startup banner** — `testing.md` §2.0 shows
  `Grbl 1.1h ['$' for help]` + `[MSG:Caution: Unlocked]`; confirm the exact
  strings the shipped build prints.

## Documentation gaps

- [ ] **No schematic / wiring diagram.** `electronics.md` describes the 5 V/GND
  distribution board and the solenoid MOSFET circuit in text + ASCII only.
  Add a proper schematic (or at least annotated photos) for: the MOSFET
  gate/flyback/pull-down circuit, and how the two X optical endstops are
  combined onto D9.

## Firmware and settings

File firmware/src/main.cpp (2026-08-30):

/*
  SPDX-License-Identifier: GPL-3.0-or-later
  Copyright (c) 2026 Simon Gerlach

  main.cpp  —  PlatformIO entry point for GRBL on the G-code Pen Plotter
  -----------------------------------------------------------------------
  This file is the Arduino-framework wrapper that calls the standard GRBL
  main() function.  All real work happens inside the GRBL C sources that
  are compiled in via platformio.ini (build_src_filter).

  Hardware summary
  ────────────────
  Board         : Arduino Uno (ATmega328P)
  Shield        : Arduino CNC Shield v3
  Axes in use   : X (carriage / pen left-right)
                  Y (paper feed / pen up-down on sheet)
  Pen lift      : Solenoid on Spindle PWM output (D11 on CNC Shield)
                  → driven via N-channel MOSFET with flyback diode
                  → controlled via G-code M3 Sxxx / M5
  Endstops      : 2× optical, wired to X_MIN (D9) and Y_MIN (D10)

  GRBL pin mapping (CNC Shield v3 → Arduino Uno)
  ──────────────────────────────────────────────
  Function          Shield label   Arduino pin
  ────────────────────────────────────────────
  X Step            X.STEP         D2
  X Direction       X.DIR          D5
  Y Step            Y.STEP         D3
  Y Direction       Y.DIR          D6
  Z Step            Z.STEP         D4  (unused)
  Z Direction       Z.DIR          D7  (unused)
  Stepper Enable    EN             D8  (active LOW → A4988 enabled)
  X min endstop     X-             D9
  Y min endstop     Y-             D10
  Spindle PWM       SpnEn/D11      D11 → pen-lift solenoid MOSFET gate
  Abort / Reset     A0
  Feed Hold         A1
  Cycle Start       A2
  Coolant / Mist    A3 / A4        (unused)
  Probe             A5             (unused)

  Microstep jumpers (MS1/MS2/MS3 under each driver on the shield)
  ────────────────────────────────────────────────────────
  All three jumpers installed → 1/16 microstepping (default assumed)
  Match DEFAULT_X/Y_STEPS_PER_MM in config.h if you change this.

  Solenoid wiring
  ───────────────
  D11 (PWM) ──[100 Ω]── MOSFET gate
  MOSFET drain ── solenoid (−)
  solenoid (+) ── 12 V
  Flyback diode across solenoid coil (cathode to +12 V)
  MOSFET source ── GND

    Pen up/down G-code (repository default)
    ───────────────────────────────
    The repository default and G-code profiles assume an "inverted" solenoid
    mounting where the solenoid being ENERGIZED = pen UP (lift). That means:

        M3 S1000  → solenoid ON  → pen UP (lift)
        M5        → solenoid OFF → pen DOWN (spring returns)

    If your hardware uses the opposite mapping (energized = pen DOWN), either
    swap M3/M5 in the G-code templates or invert the solenoid wiring.
*/

extern "C"
{
    // GRBL is written in C; we declare its main() so C++ can call it.
    int grbl_main(void);
}

// The Arduino framework calls setup() once and then loop() forever.
// We never return from grbl_main(), so setup() is the whole program.
extern "C" void setup()
{
    grbl_main(); // never returns
}

extern "C" void loop()
{
    // grbl_main() contains its own infinite loop; this is never reached.
}

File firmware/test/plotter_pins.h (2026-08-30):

/*
  SPDX-License-Identifier: GPL-3.0-or-later
  Copyright (c) 2026 Simon Gerlach

  plotter_pins.h
  ==============
  Translate GRBL pin definitions (AVR port bit numbers from cpu_map.h)
  to Arduino pin numbers.

  GRBL stores pins as bit positions within AVR I/O ports:
    PORTD bit N  →  Arduino digital pin N       (D0 – D7)
    PORTB bit N  →  Arduino digital pin N + 8   (D8 – D13)
    PORTC bit N  →  Arduino analog pin N = A0+N (A0 – A5)

  This file must be included AFTER CPU_MAP_ATMEGA328P is defined
  (set via -DCPU_MAP_ATMEGA328P in the build flags in platformio.ini)
  so that cpu_map.h activates the correct pin block.

  Usage in test sketches:
    #include "../plotter_pins.h"
*/

#pragma once

// cpu_map.h contains all bit definitions for CPU_MAP_ATMEGA328P.
// CPU_MAP_ATMEGA328P must be defined before this include
// (set via -DCPU_MAP_ATMEGA328P in the build flags of the test environments).
#include "cpu_map.h"

// ── Stepper pins (step / direction) ───────────────────────────────────────
// Bit definitions in cpu_map.h: X_STEP_BIT, Y_STEP_BIT, … on PORTD
// PORTD bit N → Arduino pin N (direct mapping for D0–D7)

#define PIN_X_STEP (X_STEP_BIT)     // PORTD bit 2 → D2
#define PIN_Y_STEP (Y_STEP_BIT)     // PORTD bit 3 → D3
#define PIN_X_DIR (X_DIRECTION_BIT) // PORTD bit 5 → D5
#define PIN_Y_DIR (Y_DIRECTION_BIT) // PORTD bit 6 → D6

// ── Enable pin (shared by all axes, active LOW) ───────────────────────────
// STEPPERS_DISABLE_BIT is on PORTB → Arduino pin = bit + 8

#define PIN_ENABLE (STEPPERS_DISABLE_BIT + 8) // PORTB bit 0 → D8

// ── Endstop pins ──────────────────────────────────────────────────────────
// X_LIMIT_BIT / Y_LIMIT_BIT are on PORTB → Arduino pin = bit + 8

#define PIN_X_MIN (X_LIMIT_BIT + 8) // PORTB bit 1 → D9  (X_MIN + X_MAX combined)
#define PIN_Y_MIN (Y_LIMIT_BIT + 8) // PORTB bit 2 → D10 (Y_LIMIT — unused, no Y endstop)

// ── Solenoid / spindle PWM pin ────────────────────────────────────────────
// SPINDLE_PWM_BIT is on PORTB → Arduino pin = bit + 8

#define PIN_SOLENOID (SPINDLE_PWM_BIT + 8) // PORTB bit 3 → D11

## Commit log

2025-09-01 Add new PNG and STL files for various components
    [Paper_guide_roll_holder.stl, Paper_intake_support.stl, carriage.stl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]
2025-09-01 Fixed readme and naming case of files
2025-09-01 Test to use embedded Stl viewer
2025-09-02 Fixed number of printed parts
2025-09-02 Added pathes to stl for readme
2025-09-02 Added screws for housing to part list and rendering
2025-09-04 Added better renderings and improved assembly instructions
2025-09-04 Added printing instructions
2025-09-04 Added funding button
2025-09-19 Added tensioned rollers
    [paper_guide_roll_fork.stl, paper_guide_roll_holder.stl]
2025-09-25 Added improved paper guide pusher and renderings. Added holes for pushbuttons in frame
    [carriage.stl, housing_back.stl, housing_front.stl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]
2025-09-25 Added assembly video
2025-09-25 Added detail assembly rendering
2025-10-03 Added updated designs for carriage and pushers
    [carriage.stl, flat_steel_lever.stl, paper_guide_lever.stl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]
2025-10-05 Reworked paper guide and simplified overall structure
    [frame_back.stl, frame_front.stl, housing_back.stl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]
2025-10-10 Minor fixes in drill holes for better fit
    [housing_back.stl, housing_front.stl]
2025-10-10 Merged both paper guide peaces into one
    [paper_guide_back.stl, paper_guide_front.stl, paper_guide_left_back.stl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]
2025-10-11 made paper guide more sturdy and slider looser for less friction when moving
    [paper_guide_back.stl, paper_guide_front.stl, solenoid_slider.stl]
2025-10-12 New cable guide for endstops. adapted carriage for more stability
    [carriage.stl, carriage_penholder_base.stl, frame_back.stl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]
2025-10-12 added cable management
    [cable_management.stl]
2025-10-12 moved endstop of carriage to not collide with cables in frame
    [carriage.stl]
2025-10-12 Added new pictures of assembly to reflect latest changes
    [housing_back.stl]
2025-10-22 Improved (less fragie) cable management
    [cable_management.stl]
2025-10-24 Added new penholder and refactored readme
    [carriage.stl, carriage_penholder_base.stl, carriage_penholder_connector_fitting.stl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]
2025-10-31 Renamed paper guide to paper bail and updated readme
    [housing feet.stl, paper_bail_lever.stl, paper_bail_pusher_back.stl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]
2025-10-31 Fixed wrong reference in BOM
2025-10-31 Made all pictures of components and assemblies automatically exported via fusion add-in
    [cable_management.stl, carriage.stl, carriage_penholder_base.stl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]
2025-11-01 Added housing feet images
    [housing_feet.stl]
2025-11-09 Added PCB holder and USB/power jack holdes in housing
    [housing_back.stl, pcb_holder.stl]
2025-11-09 more robust and easily printable housing
    [housing_front.stl]
2026-03-15 Added GRBL submodule
2026-04-12 Added first version of pipeline to process images for printing
2026-04-19 chore: move GRBL submodule into firmware/grbl and update paths/docs
2026-04-19 Repaired PIO builds after moving GRBL submodule
2026-04-19 Update pen commands in GRBL documentation and related files for consistency
2026-04-19 Fixed gcode commands for solenoid lifting/lowering in testing documenttion
2026-08-30 docs: consolidate test/commissioning docs into testing.md; mark project WIP
    - testing.md is now the single source for the whole test & commissioning
    sequence; add "Phase 0 — Prerequisites" linking assembly / wiring / install.
    - firmware/README.md: drop the duplicated Phase 1 + Phase 2 procedure (~170
    lines), replace with a pointer table to testing.md; keep firmware reference
    only (layout, build, flash, GRBL settings).
    - Move the third-party "SVG -> G-code" and "G-code sender" tool lists from
    firmware/README.md to pipeline/README.md ("Alternative tools").
    - electronics.md: shrink "Hardware verification" to a pointer to testing.md
    Phase 1.
    - README.md / firmware/README.md / electro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
2026-08-30 docs: drop stale requirements.txt/62-tests block, remove submodule gitignore line
    - .gitignore: remove firmware/grbl/ (it is a registered submodule).
    - .github/copilot-instructions.md: replace the fabricated "requirements.txt
    structure" block with a pointer to pyproject.toml; drop the "62 tests"
    figures.
    - TODO.md: check off the resolved items.
2026-08-30 docs: add per-component license structure (GPL firmware / MIT pipeline / CC BY-SA hw+docs)
    The firmware is a derivative of GRBL (GPLv3) — it reuses GRBL headers, is
    linked into one binary with the GRBL sources, and grbl_main_shim.c is copied
    from GRBL's main.c — so it must be GPL-3.0-or-later. The Python pipeline only
    talks to GRBL over serial (no shared code) and stays MIT. Hardware design and
    docs stay CC BY-SA 4.0.
    - firmware/LICENSE: GPL-3.0 full text
    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
2026-08-30 docs: drop incorrect TODO note about McMaster references
    BOM.md does list McMaster-Carr part numbers (8 rows, e.g. 6627T64,
    57155K563), so the README "McMaster/AliExpress references" wording is
    accurate — nothing to remove.
2026-08-30 docs: fix broken numbering in README assembly steps
    The list restarted at "1." after each interleaved image; renumber the
    carriage / paper-bail / housing steps to 4-6.
2026-08-30 refactor(pipeline): move step display names into the step classes
    Every step class now carries a human-readable ``name`` (e.g.
    StyliseCannyStep.name = "Canny edge detection"). display_name resolution
    is now: YAML ``label`` (per-use override) -> class ``name`` -> registry
    key -> class name.
    As a result the per-step ``label:`` lines in pipeline/configs/*.yaml
    were pure boilerplate restating the step key, so they are removed. A
    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
2026-08-30 fix(firmware+docs): reconcile machine wiring — X_MIN+X_MAX, no Y endstop, solenoid on D11
    Confirmed hardware layout:
    - 2 optical endstops, both on X (X_MIN + X_MAX), parallel on the X_LIMIT
    pin (D9). GRBL can't tell them apart -> X length is taught into $130.
    - Y has no endstop and does not home.
    - Pen-lift solenoid on D11 (GRBL spindle PWM); de-energized = pen down.
    Changes:
    - config.h: `#define VARIABLE_SPINDLE` (puts the drive on D11, moves the
    unused Z_LIMIT to D12); `HOMING_CYCLE_0 = (1 << X_AXIS)` (was X|Y);
    header + inline comments rewritten; X_MAX_TRAVEL marked as a placeholder;
    TODO comment on the unverified $5 / DEFAULT_INVERT_LIMIT_PINS value.
    Verified: `pio run` (uno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
2026-08-30 fix(pipeline): PyYAML is a core dependency (G)
    PipelineRunner.from_yaml needs PyYAML, and that is the standard entry point
    for the CLI as well as the GUI — so a bare `pip install -e pipeline/` must
    include it. Moved from the `gui` optional extra into core `dependencies`;
    `gui` now only carries the actual server deps (fastapi, uvicorn,
    python-multipart). README "Core only" note corrected.
    TODO.md: PyYAML item closed; added documentation-gap items (schematic /
    MOSFET drawing, full GRBL $$ reference + calibration, send_gcode feedback).
2026-08-30 fix(configs): rework standard_pipeline, add plotter.yaml (B, C, J)
    B — pipeline/configs/standard_pipeline.yaml was stale (wrong metadata,
    legacy gcode_gen, GUI-incompatible). Rewritten as a clean CPU-only CLI
    example (load -> canny -> vectorise -> gcode_from_svg -> save_gcode) and
    moved to pipeline/examples/. Verified: produces 3.9k-line G-code ending
    on M5 from the test image.
    C — added pipeline/configs/plotter.yaml (load -> vectorise ->
    gcode_from_svg -> send_gcode); the GUI's /api/pipelines now excludes the
    plotter stem so it isn't listed as a regular stylizer pipeline.
    J — rewrote pipeline/examples/run_examples.sh: correct paths,
    .venv/bin/pipeline-run, runs the standard pipeline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
2026-08-30 feat(send_gcode): fail the pipeline on GRBL error/alarm/timeout (option 1 + 2)
    pygrbl_streamer never raises on a GRBL error:/ALARM: — it logs them and
    (for ALARM) auto-sends $X and continues, so a bad plot looked like
    success. SendGcodeStep now records the alarm/error/disconnect callbacks
    and, after streaming, raises RuntimeError if any occurred or if GRBL is
    not back in Idle (verified with a ? status query). The runner then aborts
    and the failure propagates like any other step error.
    CLI (main.py): wrap runner.run() so a failure prints
    "✗ Pipeline FAILED: <msg>" and exits non-zero instead of dumping a raw
    traceback; success prints "✓ Pipeline OK". Uses print(), not logging —
    vpype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
2026-08-30 docs: prune two now-stale inline TODO markers
    The electronics.md endstop-count contradiction and the testing.md '62 tests'
    figure are resolved; keep only the still-open bits (tc2 sketch rework).
2026-08-30 fix(firmware): actually wire src/config.h into the build (option B)
    src/config.h was dead: nothing #included it, and grbl.h's own
    `#include "config.h"` always resolves to the submodule's sibling file.
    The firmware was 100% stock GRBL — HOMING_CYCLE_0 was (1<<Z_AXIS) then
    X|Y, i.e. `$H` would drive Z and Y with no switches.
    Now:
    - platformio.ini [env:uno]: `-include src/config.h` force-includes it.
    - src/config.h: rewritten as an override file. It `#include`s the stock
    grbl/grbl/config.h unchanged (bracketed by `#define grbl_h` / `#undef`
    to break the recursive grbl.h include), then overrides HOMING_CYCLE_0
    -> (1<<X_AXIS), undefs HOMING_CYCLE_1, and `#error`s if VARIABLE_SPINDLE
    is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
2026-08-30 test(firmware): rework TC2 for the real endstop wiring
    Both X switches (X_MIN + X_MAX) are on one pin (X_LIMIT / D9). The old
    tc2_x_endstops sketch read a phantom "X_MAX on D10". Rewritten as
    tc2_endstops: watches D9 only, drives to each end, backs off, and asks
    the operator which physical end was reached — same limitation GRBL has.
    Handles inverted module polarity (TRIGGERED_LEVEL + $5 note).
    - rename dir/file/env tc2_x_endstops -> tc2_endstops
    - platformio.ini: env + comments (also drop a duplicated header block)
    - plotter_pins.h: note D10/Y_LIMIT is unused
    - testing.md TC2 rewritten; firmware/README + electronics.md refs fixed;
    TODO item closed
    - verified: pio run for uno + all 4 tes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
    [plotter_pins.h, tc2_endstops.cpp]
2026-08-30 feat(gcode): reduced solenoid holding current in grbl_a4_pen.toml
    Each pen-up now pulls in at M3 S1000, dwells 50 ms, then holds at M3 S350
    (~35 % PWM) so the coil runs at ~1/3 power during travel moves. Applied to
    both document_start and line_end; files still end on M5.
    The S350 hold value is a starting point — flagged for on-hardware tuning
    in electronics.md and TODO.md. Verified: generated G-code carries the
    pattern; config smoke test still 4/4.
2026-08-30 docs(firmware): add GRBL.md — full $ reference + calibration
    Complete $0-$132 table with this machine's target values and per-setting
    notes, plus calibration procedures: direction ($3), steps/mm ($100/$101,
    with the belt vs. paper-feed distinction), acceleration, squaring/skew,
    and pointers to TC5b-G for $130. Linked from firmware/README (TOC +
    checklist) and testing.md. Closes the "GRBL $$ reference / calibration"
    TODO gap.

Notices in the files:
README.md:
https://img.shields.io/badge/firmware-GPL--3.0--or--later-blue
